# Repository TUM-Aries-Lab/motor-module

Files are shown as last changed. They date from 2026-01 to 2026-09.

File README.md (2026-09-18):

# Motor Control Software for Soft Exoskeleton



Motor control for the CubeMars AK60-6 actuator module used in Aries soft-exosuit development.

## Current Status

- Primary interface: CAN on Jetson Orin Nano via Linux SocketCAN
- Current maintained CAN path: MIT-only control
- Supported high-level helpers: `set_position()`, `set_velocity()`, `set_current()`, `stop()`
- UART support remains available for compatibility and earlier bring-up workflows

This repository is the motor-module codebase, not a full exosuit application. Its current focus is a modular actuator-control layer plus the bench-side scripts used to validate it.

## Key Features

- Transport-independent motor abstraction through `BaseMotor`
- Maintained SocketCAN backend for the CubeMars AK60-6
- MIT-only CAN control path with one consistent command model
- Background command refresh, feedback decoding, cached state handling, and staged recovery
- Bench-validation scripts for MIT mode, position stepping, velocity verification, and plotting

## Installation

For normal development, testing, and analysis:

```bash
uv sync --all-groups
source .venv/bin/activate
```

If you only want to install the package itself:

```bash
uv pip install -e .
```

## CAN Setup on Jetson Orin Nano

### Recommended: systemd startup

Install the tracked `can0.service` once so `can0` comes up automatically on boot:

```bash
sudo cp can0.service /etc/systemd/system/
sudo systemctl daemon-reload
sudo systemctl enable can0.service
sudo systemctl start can0.service
```

This brings `can0` up at 1 Mbps with bus-off auto-recovery.

Useful checks:

```bash
systemctl status can0.service
sudo systemctl restart can0.service
ip -details link show can0
```

### Manual setup

If you do not want to use the service, configure the interface manually:

```bash
sudo ./setup_can.sh
```

## Important Hardware Note

If the R-Link / UART cable is connected to the motor, CAN commands may be silently ignored even though feedback frames are still visible on the bus. For CAN operation, disconnect the UART cable and then reset the CAN interface.

## Recommended Workflow

### 1. Confirm MIT/CAN communication

```bash
sudo ./setup_can.sh
.venv/bin/python scripts/mit_mode_test.py --motor-id 0x03
```

### 2. Validate sustained velocity behavior

```bash
.venv/bin/python scripts/verify_set_velocity.py --motor-id 0x03 --velocity-erpm 3000
```

### 3. Run repeated MIT position stepping

```bash
.venv/bin/python scripts/mit_position_steps.py --motor-id 0x03 --duration 180 --angle-deg 50 --velocity-deg-s 100
```

### 4. Generate comparison plots from recorded CSV files

```bash
.venv/bin/python scripts/plot_graph.py velocity --data-root CSV --out-dir CSV/plots
.venv/bin/python scripts/plot_graph.py position --data-root CSV --out-dir CSV/plots
```

## Python API

The default convenience alias is the CAN motor class:

```python
from motor_python import Motor

with Motor(motor_can_id=0x03) as motor:
    motor.enable_mit_mode()
    motor.set_velocity(3000)
    motor.set_position(90.0)
    motor.stop()
```

For direct access to the specific implementations:

```python
from motor_python.cube_mars_motor_can import CubeMarsAK606v3CAN
from motor_python.cube_mars_motor import CubeMarsAK606v3
```

### Main CAN lifecycle methods

| Method | Purpose |
| --- | --- |
| `enable_mit_mode()` | Enter MIT mode |
| `disable_mit_mode()` | Exit MIT mode |
| `check_communication()` | Verify that the motor responds on the bus |
| `get_status()` | Return the latest cached `MotorState` |
| `close()` | Stop and close transport resources |

### Main CAN control methods

| Method | Purpose |
| --- | --- |
| `set_position(position_degrees)` | MIT-backed position command |
| `set_velocity(velocity_erpm)` | MIT-backed velocity command. Zero releases the motor via `stop()` |
| `set_current(current_amps)` | Interpreted as MIT torque feedforward |
| `set_mit_mode(pos_rad, vel_rad_s, kp, kd, torque_ff_nm)` | Direct MIT command |
| `stop()` | Neutral MIT command, disable MIT mode, release the motor |

## Useful Bench Scripts

These are the maintained scripts that matter most for the current implementation:

| Script | Purpose |
| --- | --- |
| `scripts/mit_mode_test.py` | Focused MIT/CAN protocol validation |
| `scripts/verify_set_velocity.py` | Bench verification of `set_velocity()` |
| `scripts/mit_position_steps.py` | Long-run MIT position stepping for bench tests |
| `scripts/plot_graph.py` | Chapter-4-style overlay and summary plots from recorded CSV files |
| `scripts/diagnose_can.py` | CAN bus diagnostics and recovery support |
| `scripts/scan_ids.py` | CAN ID discovery |
| `scripts/reset_degree.py` | Practical MIT recentering helper |

Additional exploratory and legacy scripts remain under `scripts/`, but they are not the primary maintained validation path.

## Testing

Run unit tests:

```bash
make test
```

Run CAN hardware tests:

```bash
make test-hardware-can
```

Run all hardware tests:

```bash
make test-hardware-all
```

## Project Structure

```text
can0.service                    systemd unit for automatic can0 startup
setup_can.sh                    manual CAN setup and reset helper
src/motor_python/               package source
scripts/                        bench and validation scripts
tests/                          unit and hardware-oriented tests
data/csv_logs/.gitkeep          placeholder for locally generated CSV logs
Test Rig CAD files/             CAD assets for the bench rig
```

## Notes on Scope

- The current CAN implementation is MIT-only.
- Legacy servo transport modes are intentionally not part of the maintained CAN path.
- The repository includes bench-validation tooling, but not thesis-only notes, temporary files, or local analysis artifacts.

## Run the Package Entry Point

```bash
uv run python -m motor_python
```

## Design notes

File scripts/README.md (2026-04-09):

# CAN Testing Scripts

Ad-hoc scripts for testing, diagnosing, and exercising the CubeMars AK60-6 motor over CAN.
These are **not** part of the main library or automated test suite — they are meant to be run
manually on the bench with the motor physically connected.

> **Current software status (2026-03-18): MIT-only CAN implementation.**
> For routine validation use `scripts/mit_mode_test.py` first.
> Duty/servo scripts in this folder are retained as historical diagnostics.

## Pre-conditions (all scripts)

```bash
# 1. Set PSU to 24 V and power-cycle the motor
# 2. Disconnect the UART / R-Link cable from the motor
# 3. Set up the CAN interface (run once per reboot)
sudo ./setup_can.sh

# 4. Activate the venv  — OR — prefix every script with .venv/bin/python scripts/<name>.py
source .venv/bin/activate
```

---

## Scripts

### `spin_test.py` (legacy)
Raw CAN demo — spins the motor forward for 2 s, pauses, then reverses for 2 s using
duty-cycle mode (arb_id 0x03). Prints live position/speed/current.

```bash
.venv/bin/python scripts/spin_test.py
```

---

### `motion_capture_test.py` (legacy)
Full motion-capture validation run — duty-cycle P-controller sine sweep (90 ± 30° at 6 s
period, 90 s total).  Logs telemetry to `data/logs/mocap_<timestamp>.csv`.

```bash
.venv/bin/python scripts/motion_capture_test.py
```

---

### `can_demo.py` (legacy exploration)
Exercises **every public method** of `CubeMarsAK606v3CAN` and prints PASS / FAIL / SKIP.
Use this to verify which modes work on the current firmware build.

```bash
.venv/bin/python scripts/can_demo.py
```

---

### `mit_mode_test.py`
Single-motor MIT protocol validation (CAN ID `0x03` by default). Exercises:
`enable_mit_mode`, `set_mit_mode`, `disable_mit_mode`, plus MIT-backed helpers
`set_position`, `set_velocity`, `set_current`, `stop`, and alias calls
`enable_motor` / `disable_motor`.

```bash
.venv/bin/python scripts/mit_mode_test.py
# If can0 is already configured and you don't want auto sudo reset:
.venv/bin/python scripts/mit_mode_test.py --skip-preflight
# Include velocity/current API sections (can spin the motor):
.venv/bin/python scripts/mit_mode_test.py --include-spin-tests
```

---

### `verify_set_velocity.py`
Focused validation for the `set_velocity()` API only.
It runs `start_ERPM -> 0 -> opposite_ERPM -> 0` (or start-direction only),
checks feedback sign/magnitude against the command, prints strict PASS/FAIL,
and logs each fresh feedback sample to CSV for mocap overlay.

```bash
.venv/bin/python scripts/verify_set_velocity.py --motor-id 0x03
# Signed range: -5000..5000 (starts in given direction, then reverses unless --forward-only)
.venv/bin/python scripts/verify_set_velocity.py --motor-id 0x03 --velocity-erpm -5000
# Skip automatic CAN reset if your interface is already configured:
.venv/bin/python scripts/verify_set_velocity.py --motor-id 0x03 --preflight-mode skip
# Forward-only check:
.venv/bin/python scripts/verify_set_velocity.py --motor-id 0x03 --forward-only
# Firmware-compatibility debug knobs:
.venv/bin/python scripts/verify_set_velocity.py --motor-id 0x03 --helper-policy fcfd --allow-legacy-feedback-ids
.venv/bin/python scripts/verify_set_velocity.py --motor-id 0x03 --feedback-can-id 0x2903
# Reduce velocity-loop aggressiveness if the bus drops under load:
.venv/bin/python scripts/verify_set_velocity.py --motor-id 0x03 --velocity-kd 0.12
# explicit CSV output path:
.venv/bin/python scripts/verify_set_velocity.py --motor-id 0x03 --csv-path data/csv_logs/verify_overlay.csv
```

---

### `mit_position_steps.py`
Long-run MIT position stepping script (ping-pong inside a safe angle window) so it can run for motion capture without hitting MIT position limits.
Primary knobs are still `--angle-deg`, `--duration`, and `--velocity-deg-s`.
Each command/feedback sample is also logged to CSV for direct comparison with mocap data.

```bash
# 3-minute mocap run (default behavior):
.venv/bin/python scripts/mit_position_steps.py --motor-id 0x03 --duration 180 --angle-deg 30 --velocity-deg-s 20

# faster stepping:
.venv/bin/python scripts/mit_position_steps.py --motor-id 0x03 --duration 180 --angle-deg 45 --velocity-deg-s 30

# custom sweep window (stays away from MIT hard limits):
.venv/bin/python scripts/mit_position_steps.py --motor-id 0x03 --duration 180 --angle-deg 30 --velocity-deg-s 20 --min-deg -600 --max-deg 600

# If can0 is already configured and you don't want auto reset:
.venv/bin/python scripts/mit_position_steps.py --motor-id 0x03 --duration 180 --angle-deg 30 --velocity-deg-s 20 --skip-preflight
# explicit CSV output path:
.venv/bin/python scripts/mit_position_steps.py --motor-id 0x03 --duration 180 --angle-deg 30 --velocity-deg-s 20 --csv-path data/csv_logs/mit_overlay.csv
```

> `mit_position_steps.py` uses the same kernel-level reset path as `setup_can.sh`
> for auto preflight (`berr-reporting on`, `restart-ms 100`).

---

### `reset_degree.py`
MIT-only practical reset helper: smoothly recenters the motor to a target degree
(default `0`) in MIT command space.

```bash
.venv/bin/python scripts/reset_degree.py --motor-id 0x03 --target-deg 0
# slower and gentler reset:
.venv/bin/python scripts/reset_degree.py --motor-id 0x03 --target-deg 0 --velocity-deg-s 10 --control-hz 15
# if can0 is already configured:
.venv/bin/python scripts/reset_degree.py --motor-id 0x03 --target-deg 0 --skip-preflight
```

---

### `quick_test.py`
Sends an enable command, listens for 3 s, and prints every unique CAN ID captured.
Useful for confirming the motor is on the bus and identifying the feedback ID.

```bash
.venv/bin/python scripts/quick_test.py
```

---

### `stress_test_can.py`
Runs 30 rounds of connect → enable → get_status → disable → close to verify the driver
is reliable under rapid reconnection and heavy use.

```bash
.venv/bin/python scripts/stress_test_can.py
```

---

### `diagnose_can.py`
Step-by-step diagnostic that tests each phase of the CAN connection independently:
CAN bus state → raw listen → filtered listen → enable/response → rapid cycles.
The script now reports **error-frame volume** explicitly, so `0x88` noise is
distinguished between real data frames and CAN error frames.

```bash
.venv/bin/python scripts/diagnose_can.py
```

---

### `scan_ids.py`
Scans CAN IDs 1–10 to discover which ID the motor is configured to use.
Run this if you don't know the motor's CAN ID.

```bash
.venv/bin/python scripts/scan_ids.py
```

---

### `drive_test.py`
Tries multiple duty formats, levels, and control modes (duty, current, velocity)
and records the feedback to characterise which modes the firmware supports.

```bash
.venv/bin/python scripts/drive_test.py
```

---

### `simple_test.py`
Minimal velocity spin helper for one motor: command one ERPM for one duration, then stop.
Use this when you only want to change speed and spin time quickly.

```bash
# default quick run
.venv/bin/python scripts/simple_test.py

# set only speed and duration
.venv/bin/python scripts/simple_test.py --velocity-erpm 4500 --duration 1.8

# reverse direction
.venv/bin/python scripts/simple_test.py --velocity-erpm -3000 --duration 1.2
```

---

### `tests/manual_our_implementation_test.py`
Manual integration script for the `CubeMarsAK606v3CAN` class API: enable,
feedback, velocity over 30 iterations. Good for iterating on the driver code.

```bash
.venv/bin/python tests/manual_our_implementation_test.py
```

---

### `tests/manual_servo_mode_test.py`
Legacy test using the third-party `TMotorCANControl` library's servo mode.
**Not for regular use** — kept for historical reference only.

```bash
.venv/bin/python tests/manual_servo_mode_test.py
```

---

## Two-Motor Setup (Second motor arriving Wednesday)

When the second motor arrives:
1. Set its CAN ID to **0x04** using CubeMars PC software.
2. The driver automatically assigns feedback ID `0x2904` for it.
3. Run the dual-motor demo:

```bash
.venv/bin/python -m motor_python --dual --motor-id-left 0x03 --motor-id-right 0x04
```

4. Hardware test (auto-skips until motor2 is connected):

```bash
make test-hardware-can   # includes TestCANDualMotor — skips if only one motor present
```

---

## Known Firmware Behaviour

| Mode | Works? | Notes |
|---|---|---|
| MIT (0x0803) | ✅ | Current production path in Python API |
| Duty/current/velocity/position servo frames | legacy | historical experiments only |

> Root cause of Speed=0 feedback: PSU must be **24 V**. At 18.5 V the H-bridge quietly
> locks out (error_code remains 0). Treat undervoltage and power integrity as first-line
> diagnostics when CAN feedback is present but commanded motion does not occur.

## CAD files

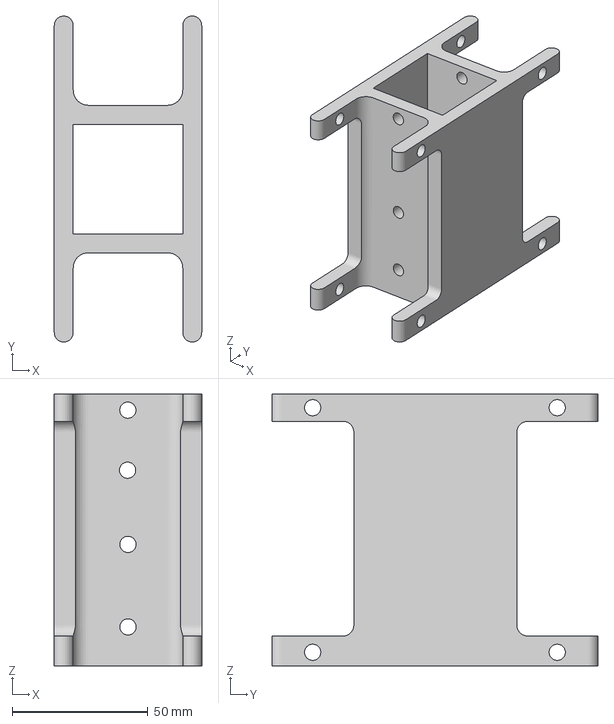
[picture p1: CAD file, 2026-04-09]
Test Rig CAD files/Rod_Adapter_Motor.3mf
54.3 x 120.0 x 100.0 mm

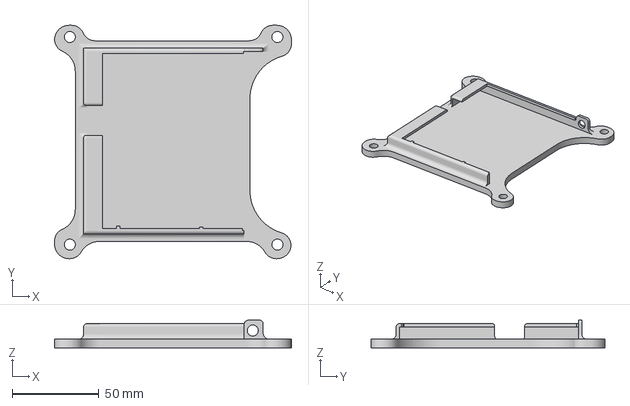
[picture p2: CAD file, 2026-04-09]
Test Rig CAD files/Jetson_Mount.3mf
137.0 x 135.0 x 16.0 mm

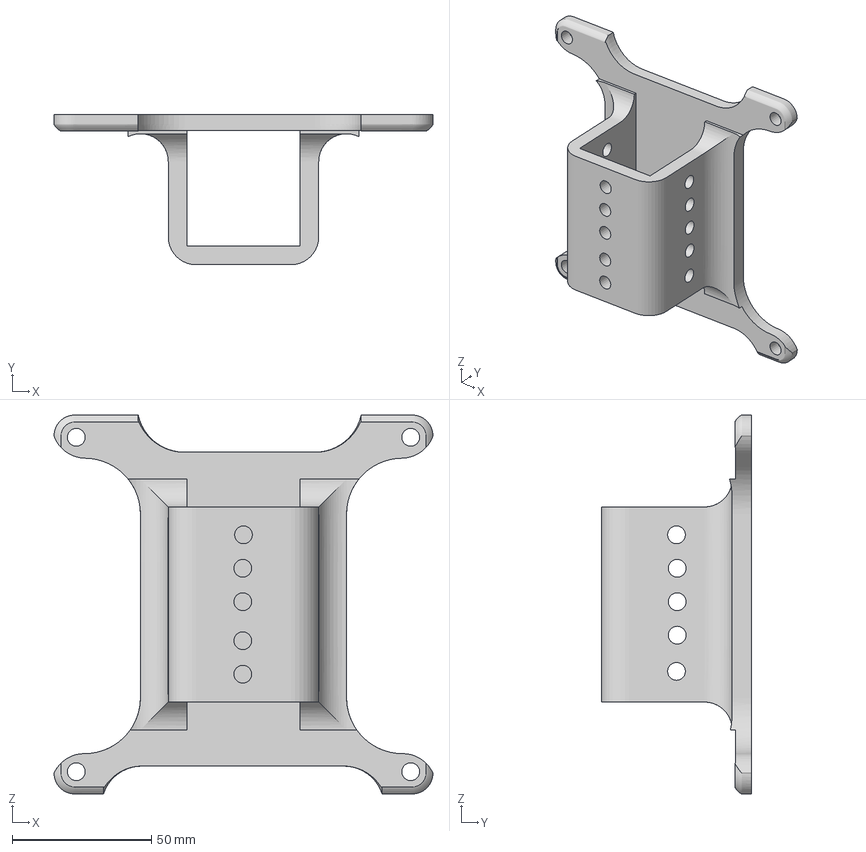
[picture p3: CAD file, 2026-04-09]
Test Rig CAD files/Rod_Adapter_Jetson.3mf
136.0 x 54.0 x 136.0 mm

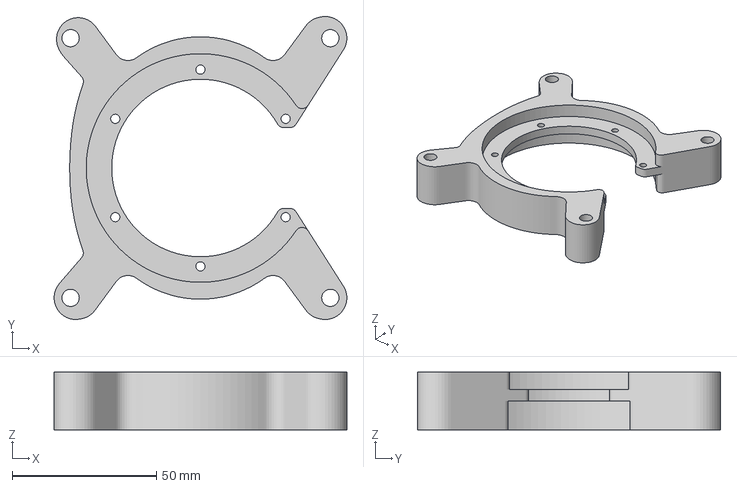
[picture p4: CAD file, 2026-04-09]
Test Rig CAD files/Motor_Case.3mf
101.4 x 105.0 x 20.0 mm

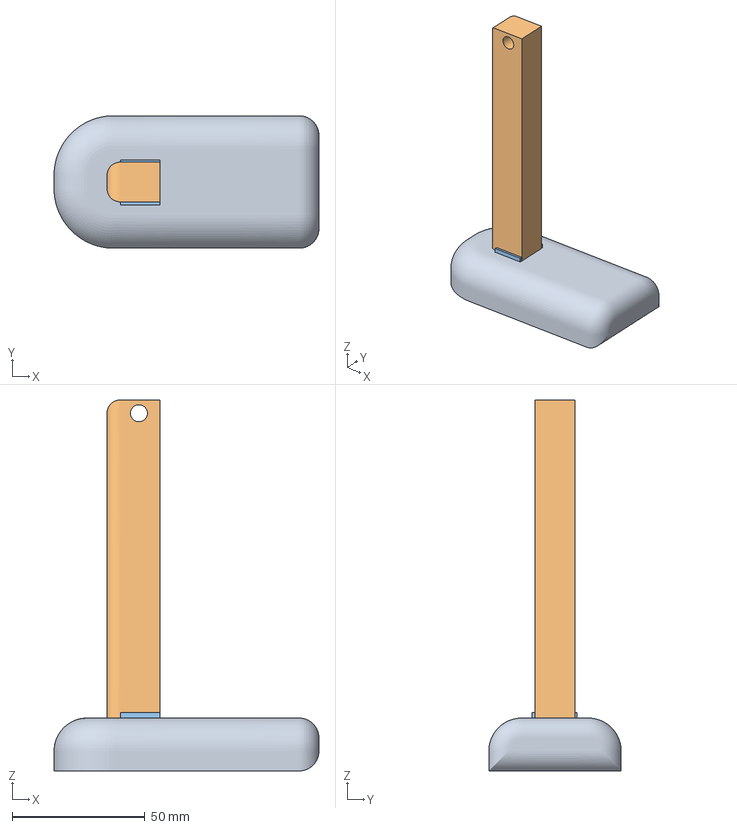
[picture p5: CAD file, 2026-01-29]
Test Rig CAD files/Foot.3mf
100.0 x 50.0 x 140.0 mm
Körper1
Körper2
Körper4

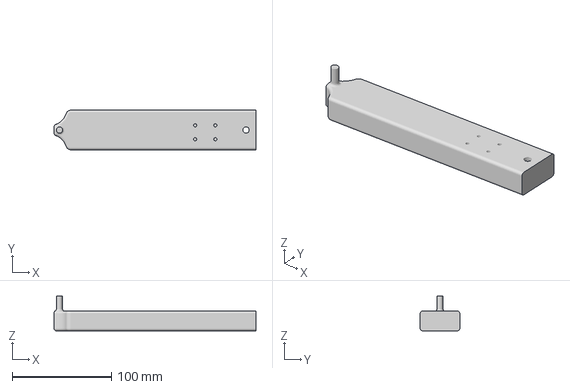
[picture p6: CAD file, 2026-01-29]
Test Rig CAD files/Leg_with_2_IMU's.3mf
203.4 x 40.0 x 35.0 mm

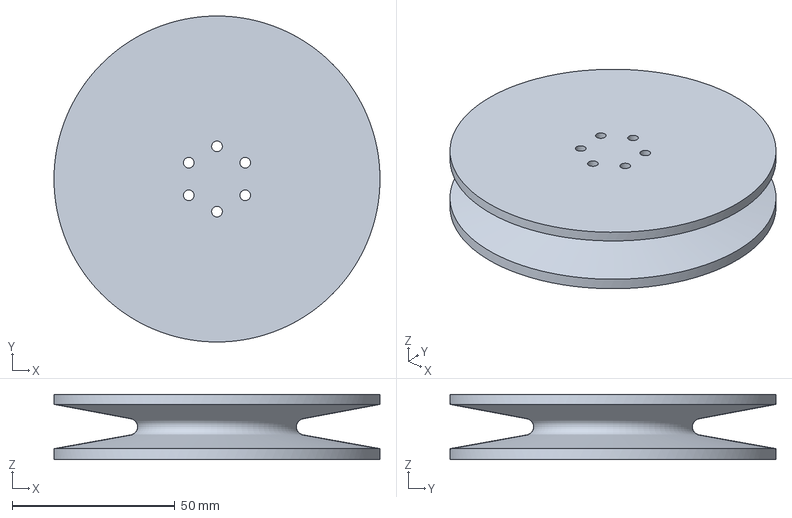
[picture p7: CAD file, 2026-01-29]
Test Rig CAD files/Spool_V2.3mf
100.0 x 100.0 x 20.0 mm

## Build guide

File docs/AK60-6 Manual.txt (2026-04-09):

AK Series Module Product Manual
                                        V3.0.1

              1 / 54
                        E-mail:info@cubemars.com
                       https://www.cubemars.com/

                                                               Content
Content....................................................................................................................................... 2
Precautions................................................................................................................................. 4
Product Features........................................................................................................................ 4
Disclaimer................................................................................................................................... 4
Version Change Record...............................................................................................................5
1. Driver Product Information.................................................................................................... 7
   1.1Driver Appearance Introduction & Product Specifications(small).................................... 7
   1.2Driver Appearance Introduction & Product Specifications(big)........................................8
   1.2Driver Interface and Definition..........................................................................................9
       1.2.1Driver Interface Diagram............................................................................................ 9
       1.2.2Driver Interface Pin Definition....................................................................................9
       1.2.3Recommended Brands and Models for Driver Interface........................................... 9
   1.3 Driver Indicator Light Definition..................................................................................... 10
   1.4         Main Accessories and Specifications........................................................................ 10
2.Connection.............................................................................................................................12
   2.1 R-link Appearance Introduction, Product Specifications, and Interface Definition....... 12
   2.3 R-link Indicator Light Definition......................................................................................13
   2.4Driver and R-link Connection and Precautions................................................................13
3.Upper Computer Instructions................................................................................................14
   3.1Upper Computer Interface and Instructions................................................................... 14
       3.1.1Configuration............................................................................................................ 15
       3.1.2Real-time Status........................................................................................................19
       3.1.3Real-time Data.......................................................................................................... 20
       3.1.4Chinese-English Switch............................................................................................. 20
       3.1.5Control...................................................................................................................... 21
       3.1.6Connect.....................................................................................................................23
       3.1.7Stop...........................................................................................................................23
   3.2Driver Board Calibration.................................................................................................. 23
       3.2.1 Calibration Steps......................................................................................................23
   3.3Control Demonstration....................................................................................................24
                                                                     2 / 54
                                                                                                            E-mail:info@cubemars.com
                                                                                                           https://www.cubemars.com/

     3.3.1Servo Mode...............................................................................................................24
     3.3.2Force Control(MIT) Mode.........................................................................................28
  3.4Firmware Update.............................................................................................................30
4. Driver Board Communication Protocol and Instructions..................................................... 31
  4.1Servo Mode Control Mode and Instructions...................................................................31
     4.1.1Duty Ratio Mode.......................................................................................................32
     4.1.2Current Loop Mode.................................................................................................. 33
     4.1.3Current Brake Mode................................................................................................. 33
     4.1.4Velocity Loop Mode..................................................................................................35
     4.1.5Position Loop Mode..................................................................................................35
     4.1.6Setting Origin Mode................................................................................................. 36
     4.1.7Position Velocity Loop Mode....................................................................................37
  4.2Force Control Mode Communication Protocol............................................................... 37
  4.3Motor Message Format................................................................................................... 42
     4.3.1 CAN Upload Message Protocol................................................................................42
     4.3.2Serial Port Message Protocol....................................................................................43
  4.4Control Command Examples........................................................................................... 52
     4.4.1 CAN Port Control Command Examples....................................................................52
     4.4.2Serial Port Control Command Examples.................................................................. 53

                                                              3 / 54
                                                                                                   E-mail:info@cubemars.com
                                                                                                  https://www.cubemars.com/

Precautions
1.Ensure that there are no short circuits in the circuit and that interfaces are connected correctly
as required.

2.    The driver board will heat up during output; please use it carefully to avoid burns.

3.    Before use, please check if all parts are intact. If any parts are missing or aged, please stop
using it and contact technical support in time.

4.     Please strictly follow the working voltage, current, temperature, and other parameters
specified in this document; otherwise, it will cause permanent damage to the product!

Product Features
The AK series motor driver board adopts high-performance drive chips in the same class, uses
Field Oriented Control (FOC) algorithm, and is equipped with advanced self-disturbance control
technology for speed and angle control. It can be used with CubeMarsTool parameter setting
software for parameter setting and firmware upgrades. In terms of hardware, the inner loop uses
a 16-bit high-precision encoder, supporting up to 21 bits (custom firmware required), and the
CAN communication uses a safer isolated CAN interface, along with a more reliable plug, greatly
enhancing the reliability of the product's use and communication; in terms of software, the
upper computer CubeMarsTool has been fully upgraded, and there is no need to switch between
servo mode and force control mode, the control interface is more concise, and a large number of
simplifications have been made in the operation, fully improving the customer's experience.

Disclaimer
Thank you for purchasing the AK series modular motor. Before using it, please read this
statement carefully. Once used, it is considered as recognition and acceptance of all the contents
of this statement. Please strictly follow the product manual and relevant laws, regulations,
policies, and guidelines for the installation and use of the product. During the use of the product,
the user promises to be responsible for their own actions and all consequences arising
therefrom.

Any losses caused by improper use, installation, or modification of the product by the user,
CubeMars will not assume legal responsibility.

CubeMars is a trademark of Nanchang Kude Intelligent Technology Co., Ltd. and its affiliated
companies. The product names and brands mentioned in this document are trademarks of the
companies. This product and manual are copyrighted by Nanchang Kude Intelligent Technology
Co., Ltd. No copying or reprinting is allowed without permission. The final interpretation of the

                                                  4 / 54
                                                                           E-mail:info@cubemars.com
                                                                          https://www.cubemars.com/

disclaimer belongs to Nanchang Kude Intelligent Technology Co., Ltd.

Version Change Record
            Date                            Version                            Change
                                                                  1.First compile
         2023.10.18                         Ver.2.0.0             2.Driver version :V3.0
                                                                  3.CubeMarsTool version:V2.0
                                                                  1.1Changed the maximum
                                                                  working voltage to the
                                                                  allowable working voltage
                                                                  range
                                                                  4.1.6Modified the example
         2024.07.29                         Ver.2.0.1             code for setting the origin
                                                                  4.2 Modified the motion
                                                                  control protocol example code
                                                                  4.3.2.1 Corrected the outer
                                                                  loop position formula

                                                                  Modified the cover logo
                                                                  1 Modified driver board
                                                                  product information
                                                                  2 Added section content
         2024.08.06                         Ver.2.0.2
                                                                  3.4Corrected the firmware
                                                                  update example picture
                                                                  4.2 Modified parameter range

                                                                  1.2.2 Corrrect drive interface
                                                                  definition
                                                                  2. Correct R-Link definition
                                                                  2.1 Add VCC voltage selction
         2024.12.04                         Ver.2.0.3             switch,modify R-link
                                                                  specifications
                                                                  3.Change CubeMars’s
                                                                  ownership to Nanchang Kude
                                                                  Intelligent Technology CO., Ltd.
                                                                  The formal version change
         2024.12.11                         Ver.3.0.0
                                                                  to3.0.0
                                                                  4.2 Add AKE60-8 and AKE80-8
                                                                  motor parameters and correct
         2025.03.14                        Ver. 3.0.1
                                                                  MIT control code routines
                                                                  4.3.2 Modify serial port control

                                              5 / 54
                                                                         E-mail:info@cubemars.com
                                                                        https://www.cubemars.com/

         data description

6 / 54
                E-mail:info@cubemars.com
               https://www.cubemars.com/

1. Driver Product Information

1.1Driver Appearance Introduction&Product Specifications（Small Size）

                                                      ①Three-phase wires connection port

                                                      ②Hardware version

                                                      ③Connection port

                                                      ④Mounting holes

                                Production specifications（small size）

      Rated working voltage                            48V

      Allowable working voltage                        18-52V

      Rated working current                            10A

      Maximum current                                  30A

      Standby power consumption                        ≤50mA

      CAN bus bit rate                                 1Mbps

      Size                                             54mm×54mm

      Working environment temperature                  -20℃ to 65℃

      Maximum allowable temperature for
                                                       100℃
control board

      Inner loop encoder bits                          21bit（single turn absolute）

     Outer loop encoder bits (limited to dual
                                                       15bit（single turn absolute）
encoder model)

                                             7 / 54
                                                                         E-mail:info@cubemars.com
                                                                        https://www.cubemars.com/

1.2Driver Appearance Introduction&Product Specifications（Big Size）

                                                           ①Three-phase wires connection

                                                    port

                                                           ②Hardware version

                                                           ③Connection Port

                                                           ④Mounting holes

                                Product Specifications（Big size）

      Rated working voltage                                48V

      Allowable working voltage                            18-52V

      Rated working current                                20A

      Maximum current                                      60A

      Standby power consumption                            ≤50mA

      CAN bus bit rate                                     1Mbps

      Size                                                 63mm×57mm

      Operation environment temperature                    -20℃ to 65℃

      Maximum allowable temperature for
                                                           100℃
control board

      Inner loop encoder bits                              21bit（single turn absolute）

     Outer loop encoder bits (limited to dual
                                                           15bit（single turn absolute）
encoder model)

                                           8 / 54
                                                                        E-mail:info@cubemars.com
                                                                       https://www.cubemars.com/

1.2 Driver Interface and Definition

1.2.1 Driver Interface Diagram

                                        Small Size

                                         Big Size

1.2.2 Driver Interface Pin Definition

                                           9 / 54
                                                      E-mail:info@cubemars.com
                                                     https://www.cubemars.com/

1.2.3 Recommended Brands and Models for Driver Interface

1.3Driver Indicator Light Definitions

                                       Indicator Light

            1.Power Indicator     Light on          The driver board is powered
            Light (Blue when
                                  Light off       The driver board is not powered
                  lit)）
              2.Operation         Light on               The motor is working
             Indicator Light
                                  Light off             The motor is not working
            (Green when lit)
              3.Drive Fault       Light on                 Driver board fault
           Indicator Light (Red
                                  Light off        Driver board function normally
                when lit)

⚠：After the driver board is powered, the blue light should remain on in the normal
state, and the green and red lights should light up for 2 seconds before going out.

                                              10 / 54
                                                                           E-mail:info@cubemars.com
                                                                          https://www.cubemars.com/

1.4 Main Accessories and Specifications

No.   Item                             Specifications                     Quantity   Remarks
                              16AWG - Red and black silicone wire and
                     Power             white and blue - Teflon
                                                                            1PCS
 1                   and      30#-OD0.64-100±10mm-4-XT30(2+2)-F-on                      ±2MM
                               e end connector XT30(2+2)-F,the other        Each
      Power and      CAN
                                  end stripped and tinned 3±1mm
      signal plug    cable
                     Serial                  Teflon30#
                     port     Wire OD0.64-200±10mm-3-GH1.25-3PINm           1PCS
 2                   cable                                                  Each        ±2MM
                              ale to FC crimp terminal horn plug 2*4PIN
 3    Thermistor                MF51B103F3950-10K-3950                      2PCS
                                                                                       AK10-9
      Electrolytic                                                                       V3.0
 4     capacitor                   120Uf-63V-10x12MM                        2PCS
                                                                                      standard
 5    Power MOS                HYG035N08NS2C2-80V-2.8mΩ                    12PCS

                                            11 / 54
                                                                       E-mail:info@cubemars.com
                                                                      https://www.cubemars.com/

2.Connection

2.1 R-link Appearance Introduction&Product Specifications and Interface

Definition

                                        Product Specifications

         Rated working voltage                            5V

         VCC voltage selection switch                     3.3v (default)

         Standby power consumption                        ≤30mA

         Size                                             73.8x23.6x14.5MM

         Working environment temperature                  -20℃ to 65℃

          Maximum Allowable Temperature for
                                                          85℃
    Control Board

           Interface
No                           Pin        Description
           Function
                             1          Serial signal imput（RXD）
                             2          Serial signal output（TXD）
                             3          Serial signal ground (GND)
           Serial            4          VCC power output（VCC）
1
           Interface         5          Data sent request（RTS）
                             6          Clear to send（CTS）
                             7          Power ground（GND）
                             8          5V Power output（5V）

                                                12 / 54
                                                                            E-mail:info@cubemars.com
                                                                           https://www.cubemars.com/

2.2 R-link Indicator Light Definitions

 No.                             Color                           Description

                                                                 PWR Power Indicator,
                                                                 indicates the power status of
                                                                 the R-link. Under normal
                                                                 conditions, it will light up red
                                                                 when power is connected. If
 1                               Red
                                                                 it does not light up when
                                                                 power is connected, please
                                                                 remove the power source
                                                                 immediately and do not
                                                                 attempt to power on again.
                                                                 TXD Serial Communication
                                                                 Output (TX), usually off,
 2                               Red                             blinks when there is data
                                                                 output from the R-link serial
                                                                 port.
                                                                 RXD Serial Communication
                                                                 Input (RX), usually off, blinks
 3                               Red
                                                                 when there is data input to
                                                                 the R-link serial port.

2.3 Driver and R-link Connection and Precautions

- USB on R-Link ---> PC End
- 8 Pin Port ---> RLink 8Pin Port End
- 3Pin Terminal (UART interface) ---> 3Pin Port on Motor(UART)

                                             13 / 54
                                                                         E-mail:info@cubemars.com
                                                                        https://www.cubemars.com/

3.Upper Computer Instruction

3.1Upper Computer Interface and Explanation

A. Configuration
B. Real-time Status
C. Real-time Data
D. Chinese-English Switch
E. Control
F. Connection
G. Stop

                                14 / 54
                                               E-mail:info@cubemars.com
                                              https://www.cubemars.com/

3.1.1 Configuration

3.1.1.1 Basic Settings

The Basic Settings interface allows users to configure motor parameters and communication
parameters; The Motor Settings section supports motor parameter identification, encoder
parameter calibration, and parameter reading and writing. For specific motor calibration
operations, see section 3.2. The Application Settings section supports settings for CAN port mode,
CAN bus rate, CAN feedback rate, CAN ID, and serial port baud rate, which users can match
according to actual conditions.

The CAN port mode is divided into two types: periodic feedback and query-reply. Periodic
reporting will provide messages at regular intervals based on the CAN feedback rate; the
query-reply mode only sends back message reports when the motor receives the correct control
commands.

                               ：Perform motor parameter identification, which can be observed in

the position curve to see if the motor is moving. After identification, it will automatically stop and
update the motor parameters to the upper computer.

                                                15 / 54
                                                                            E-mail:info@cubemars.com
                                                                           https://www.cubemars.com/

⚠ ： The entire process of motor parameter identification should be kept under no-load
conditions; otherwise, it may lead to inaccurate identification parameters or motor damage.
The identification process will start with a sharp, short sound, then the motor starting to rotate
with a louder noise.

                                ：Perform encoder parameter identification, which can be observed

in the position curve to see if the motor is moving. After identification, it will automatically stop
and update the encoder parameters to the upper computer.

⚠ ： The entire process of motor parameter identification should be kept under no-load
conditions; otherwise, it may lead to inaccurate identification parameters or motor damage.
The identification process will start with a sharp, short sound. Performing this process
consecutively multiple times can cause the motor temperature to rise sharply.

                    ：Read the motor parameters and encoder parameters from the driver board

to the upper computer.

                    ： Write the motor parameters and encoder parameters from the upper

computer to the driver board.

3.1.1.2 Advanced Settings
⚠ ： Warning. Note that customers who are using this product for the first time should not
arbitrarily modify the parameters in the advanced settings, otherwise, the motor may run
abnormally.

                                               16 / 54
                                                                           E-mail:info@cubemars.com
                                                                          https://www.cubemars.com/

The Advanced Settings interface allows users to customize more parameters according to their
needs. In addition to the parameter reading and writing functions, it also provides parameter
restoration, loading, and exporting functions.

             Read Parameters: Click to read the parameters from the driver board to the upper

computer.

             Click to write the current upper computer parameters to the driver board.

⚠：Before rewriting motor parameters, be sure to read the parameters first; otherwise, other
motor parameters will be incorrect. If this happens, please download the APP parameters for
the corresponding motor from the official website, and then write the default parameters of
the motor through "Load from file"

             Click to restore the upper computer parameters to the default values for the

corresponding model.

                                            17 / 54
                                                                       E-mail:info@cubemars.com
                                                                      https://www.cubemars.com/

                  Load the parameter file into the upper computer; click and select the

parameter file for the corresponding motor model, which comes in two formats: .AppParams
and .McParams.

               Export parameters：Click to export parameters, select the save file, and you will

obtain a custom parameter file.

⚠：Please strictly use the specified voltage, current, power, and temperature. Our company will
not assume any legal responsibility for personal injury or irreversible damage to the driver
board and motor caused by the improper operation of this product.

                                            18 / 54
                                                                       E-mail:info@cubemars.com
                                                                      https://www.cubemars.com/

3.1.1.3 Firmware Upgrade

The Firmware Upgrade interface includes three sections: Firmware Information, Upgrade Options,
and Upgrade Progress. Customers can upgrade firmware based on their own needs. For specific
steps on upgrading the firmware, see section 3.4.

3.1.2 Real-time Status

The Real-time Status interface displays the current software and hardware versions, motor
firmware version, motor parameter status, operating mode, and fault status.

                                            19 / 54
                                                                      E-mail:info@cubemars.com
                                                                     https://www.cubemars.com/

3.1.3 Real-time Data

This page supports viewing real-time data feedback and debugging interface, as well as plotting
graphs. The data includes:
-DQ: DQ voltage represents the motor voltage converted onto the D-axis and Q-axis, and DQ
current represents the motor current converted onto the D-axis and Q-axis.
- Current: Current in indicates the motor's input current, Current motor indicates the motor's
phase line current, and Duty cycle indicates the motor's duty ratio.
- Temperature: Temperature MOSFET indicates the temperature of the motor's MOS transistor,
and Temperature Motor indicates the motor's temperature.
- Speed: ERPM indicates the electrical rotational speed of the motor's rotor.
- Position: Position indicates the position of the motor's rotor.
- Encoder Angle: Encoder angle indicates the angle of the encoder.

3.1.4 Chinese-English Switch

The upper computer currently supports switching between Chinese and English languages. Click
on "中" or "EN" in the red box in the upper right corner of the interface to switch languages.

                                              20 / 54
                                                                          E-mail:info@cubemars.com
                                                                         https://www.cubemars.com/

3.1.5 Control

3.1.5.1 Servo Control

                        ： In the position-velocity loop mode, the motor can be set to positions
ranging from -36000° to 36000°;

                        ： In the position-speed loop mode, the motor can be set to positions
ranging from 0 to 359°;

                        ：The motor will set the current rotor position as the zero position;

                        ：The motor rotates to the zero position. (The motor will operate at the
maximum speed, pay attention to safety)

      ：The corresponding mode start button.

                                               21 / 54
                                                                           E-mail:info@cubemars.com
                                                                          https://www.cubemars.com/

3.1.5.2   Force Control (MIT) Control

Force control mode (motion control mode, MIT MODE) offers three different control modes:
position, speed, and torque loops, which are determined by the data sent. For specific operation
methods, see section 3.3.2.

3.1.5.3 Unit Settings

                                    :Each button corresponds to the unit that needs to be
converted, supporting the conversion display of rotational speed (RPM, ERPM, rad/s, Dps).

                                    :Enter the number of motor poles, as shown in the left figure,
14 is the number of pole pairs.

                                   :Enter the motor reduction ratio.

                                              22 / 54
                                                                         E-mail:info@cubemars.com
                                                                        https://www.cubemars.com/

3.1.6 Connection

The Connection module can configure serial communication, as shown in the left figure. First,
click "Refresh", then select the communication baud rate, choose the correct port, and finally
"Connect" of the motor. The display changes from "Not connected" to "Connected to COMX"
indicating a successful serial connection. As shown in the right figure, click "Disconnect" to
disconnect the communication.

3.1.7 Stop

The experimental stop button, when clicked, will stop the motor's working.

3.2 Driver Board Calibration
When you have reinstalled the driver board on the motor, changed the wiring sequence of the
motor's three-phase lines, or updated the firmware, recalibration is necessary (it was calibrated
when it left the factory for the first time, no need to calibrate again). After calibration, the motor
can be used.

3.2.1 Calibration Steps

                                                23 / 54
                                                                            E-mail:info@cubemars.com
                                                                           https://www.cubemars.com/

STEP0:
Ensure that the motor's power supply is stable, the connectors are properly connected, and
successfully connected to the upper computer, then enter the system settings page.
STEP1:
Click "Read" and wait for the connection interface to display.
                               ；
STEP2:
Click "Motor Identification", after a brief beep                            ； the motor will start
rotating. Wait for about 10 seconds                     before   the     motor stops rotating.
                             When the display appears, it indicates that the motor parameter
identification process is complete.

STEP3:
Click "Encoder Identification", the motor will rotate slowly. Wait for about 45 seconds, and when
the connection interface display is complete                               the encoder parameter
identification is finished.

STEP4:
Click      "Write",    and      when        the         connection      interface     display     is
complete                                 the calibration is finished.

⚠：The entire process of motor parameter and encoder parameter identification should be kept
under no-load conditions; otherwise, it may lead to inaccurate identification parameters or
motor damage. The encoder parameter identification process generates heat, and performing
this process consecutively multiple times can cause the motor temperature to rise sharply.

3.3 Control Demonstration
After confirming that the motor power supply and load are correctly installed, the wiring is
correct, and the driver board calibration is complete, you can start using the motor. Below are
explanations for the use of servo control and force control modes.

3.3.1 Servo Mode

3.3.1.1 Multi-Position-Velocity Loop Mode
Ensure that the motor input power is stable, the connectors are properly connected, and
successfully connected to the upper computer. In the "Servo Control" interface, click on "Multi
Mode," enter the desired position (at this time, the position is ± 100 turns, i.e., -36000 °
-36000 ° ), desired speed, and acceleration. The motor will move at the desired speed until it
reaches the desired position.

                                              24 / 54
                                                                            E-mail:info@cubemars.com
                                                                           https://www.cubemars.com/

3.3.1.2 Single-Position-Velocity-Loop Mode Mode
Ensure that the motor input power is stable, the connectors are properly connected, and
successfully connected to the upper computer. In the "Servo Control" interface, click on "Single
Mode," enter the desired position (at this time, the position is only one turn, i.e., 0 ° -359 ° ),
desired speed, and acceleration. The motor will move at the desired speed until it reaches the
desired position.

3.3.1.3 Braking Mode
Ensure that the motor input power is stable, the connectors are properly connected, and
successfully connected to the upper computer. In the "Servo Control" interface, enter the desired
torque T, and the motor will brake with the desired torque.

                                              25 / 54
                                                                          E-mail:info@cubemars.com
                                                                         https://www.cubemars.com/

3.3.1.4 Position Loop Mode
Ensure that the motor input power is stable, the connectors are properly connected, and
successfully connected to the upper computer. In the "Servo Control" interface, enter the desired
position P, and the motor will reach the desired position with maximum speed and acceleration.

3.3.1.5 Current Loop Mode

Ensure that the motor input power is stable, the connectors are properly connected, and
successfully connected to the upper computer. In the "Servo Control" interface, enter the
desired current I, and the motor will operate at the desired current.

                                             26 / 54
                                                                         E-mail:info@cubemars.com
                                                                        https://www.cubemars.com/

3.3.1.6 Velocity Loop Mode
Ensure that the motor input power is stable, the connectors are properly connected, and the
motor is in servo mode. After successfully connecting to the upper computer, in the "Servo
Control" interface, enter the desired speed S (±50000 ERPM), and the motor will operate at the
desired speed (with the default maximum acceleration).

3.3.1.7 Braking Loop Mode
Ensure that the motor input power is stable, the connectors are properly connected, and
successfully connected to the upper computer. In the "Servo Control" interface, enter the desired
braking current B, and the motor will brake with the desired current.

                                             27 / 54
                                                                        E-mail:info@cubemars.com
                                                                       https://www.cubemars.com/

3.3.1.8 Duty Cycle Mode
Ensure that the motor input power is stable, the connectors are properly connected, and the
motor is in servo mode. After successfully connecting to the upper computer, in the "Servo
Control" interface, enter the desired duty cycle (default 0.005-0.95), and the motor will operate
at the desired duty cycle.

3.3.2 Force Control Mode(Mit Control)

3.3.2.1Force Control Position Mode
Ensure that the motor input power is stable, the connectors are properly connected, and
successfully connected to the upper computer. In the "MIT Control" interface, enter the
corresponding "CAN ID," desired position, and KP, KD, then click "Start," and the motor will move
to the desired position. (The motor operates with a specified position and Kp, Kd values, turning
                                             28 / 54
                                                                        E-mail:info@cubemars.com
                                                                       https://www.cubemars.com/

towards the specified position)

3.3.2.2 Force Control Velocity Mode
Ensure that the motor input power is stable, the connectors are properly connected, enter the
desired speed S and KD, then click "Start," and the motor will operate at the specified speed. (The
motor operates with a specified speed and Kd value, rotating at the specified speed)

3.3.2.3 Force Control Torque Mode
Ensure that the motor input power is stable, the connectors are properly connected, enter the
desired torque T, then click "Start," and the motor will operate at the specified torque. (The
motor operates with a specified torque value, rotating at the specified torque value)
                                              29 / 54
                                                                          E-mail:info@cubemars.com
                                                                         https://www.cubemars.com/

3.4Firmware Update

1. Select the corresponding firmware from the drop-down list.
2. Click "Jump to IAP."
3. Click "Upload" and wait for the upgrade progress bar to reach 100%.
4. Click "Jump to App," wait for 5 seconds, the motor enters the operating mode, and the
firmware update is complete.

                                         30 / 54
                                                                  E-mail:info@cubemars.com
                                                                 https://www.cubemars.com/

4. Driver Board Communication Protocol and Description

4.1Servo Mode Control Modes and Description

There are 6 control modes in the servo mode, each corresponding to a specific ID number.

Duty Cycle Mode: A specified duty cycle voltage is given to the motor, similar to square wave
drive form;
Current Loop Mode: A specified Iq current is given to the motor, and since the motor output
torque = iq*KT, it can be used as a torque loop (KT data can be referenced on the official
website);
Current Brake Mode: A specified braking current is given to the motor to hold it in the current
position (pay attention to motor temperature when using);
Velocity Mode: A specified operating speed is given to the motor (acceleration is default to the
maximum value);
Position Mode: A specified position is given to the motor, and the motor will move to the
specified position (speed and acceleration are default to the maximum value);
Position-Velocity Loop Mode: A specified position, speed, and acceleration are given to the
motor.

Servo mode driver board data transmission definition
Identifier: Control Mode ID + Driver ID        Frame Type: Extended Frame
Frame Format: DATA                        DLC: 8 bytes
The servo motor protocol is a CAN protocol, using an extended frame format as shown below:

Can ID bits               [28]-[8]                               [7]-[0]
Field name (Function      Control mode ID （Control               Drive ID （Driver ID）
Definition)               ModeID）

Control mode has{0,1,2,3,4,5,6}      7 characteristic values corresponding to 7 control modes.

Duty Cycle Mode: 0
Current Loop Mode: 1
Current Brake Mode: 2
Velocity Mode: 3
Position Mode: 4
Set Origin Mode: 5
Position-Speed Loop Mode: 6

The following provides examples of controlling the motor in various modes.

                                               31 / 54
                                                                            E-mail:info@cubemars.com
                                                                           https://www.cubemars.com/

Below are library call, function and macro definitions for various instances.
typedef enum {
     CAN_PACKET_SET_DUTY = 0,                // Duty Cycle Mode
     CAN_PACKET_SET_CURRENT,                 // Current Loop Mode
     CAN_PACKET_SET_CURRENT_BRAKE,             // Current Brake Mode
     CAN_PACKET_SET_RPM,                      // Speed Mode
     CAN_PACKET_SET_POS,                       // Position Mode
     CAN_PACKET_SET_ORIGIN_HERE,               // Set origin position mode (zero mode)
     CAN_PACKET_SET_POS_SPD,                   // Position-Velocity Loop Mode
} CAN_PACKET_ID;

void comm_can_transmit_eid(uint32_t id, const uint8_t *data, uint8_t len) {
     uint8_t i=0;
     if (len > 8) {
           len = 8;
     }
     CanTxMsg TxMessage;
     TxMessage.StdId = 0;
     TxMessage.IDE = CAN_ID_EXT;
     TxMessage.ExtId = id;
     TxMessage.RTR = CAN_RTR_DATA;
     TxMessage.DLC = len;
     for(i=0;i<len;i++)
           TxMessage.Data[i]=data[i];
     CAN_Transmit(CHASSIS_CAN, &TxMessage); //CAN port trasmissionTxMessage Data Can
port sends TxMesage Data
}

void buffer_append_int32(uint8_t* buffer, int32_t number, int32_t *index) {
     buffer[(*index)++] = number >> 24;
     buffer[(*index)++] = number >> 16;
     buffer[(*index)++] = number >> 8;
     buffer[(*index)++] = number;
}

void buffer_append_int16(uint8_t* buffer, int16_t number, int16_t *index) {
     buffer[(*index)++] = number >> 8;
     buffer[(*index)++] = number;
}

4.1.1 Duty Cycle Mode
Duty Cycle Mode Data Transmission Definition

                                               32 / 54
                                                                          E-mail:info@cubemars.com
                                                                         https://www.cubemars.com/

    Data Bit             Data[0]              Data[1]              Data[2]               Data[3]

     Range               0~0xff                0~0xff              0~0xff                 0~0xff

 Corresponding        Duty Cycle Bit       Duty Cycle Bit      Duty Cycle Bit         Duty Cycle Bit
    Variable             25-32                17-24                9-16                    1-8

void comm_can_set_duty(uint8_t controller_id, float duty) {
     int32_t send_index = 0;
     uint8_t buffer[4];
     buffer_append_int32(buffer, (int32_t)(duty * 100000.0), &send_index);
     comm_can_transmit_eid(controller_id |
                    ((uint32_t)CAN_PACKET_SET_DUTY << 8), buffer, send_index);
}

4.1.2 Current Loop Mode
Current Loop Mode Data Transmission Definition

    Data Bit             Data[0]              Data[1]              Data[2]               Data[3]

     Range               0~0xff                0~0xff              0~0xff                 0~0xff

 Corresponding
                    Current Bit 25-32     Current Bit 17-24    Current Bit 9-16       Current Bit 1-8
    Variable
The current value is of int32 type, and the values -60000 to 60000 represent -60 to 60 A.
Current Loop Mode Send Example Routine

void comm_can_set_current(uint8_t controller_id, float current) {
     int32_t send_index = 0;
     uint8_t buffer[4];
     buffer_append_int32(buffer, (int32_t)(current * 1000.0), &send_index);
     comm_can_transmit_eid(controller_id |
                    ((uint32_t)CAN_PACKET_SET_CURRENT << 8), buffer, send_index);
}

4.1.3 Current Brake Mode
 Current Brake Mode Data Transmission Definition

   Data Bit           Data[0]               Data[1]                Data[2]               Data[3]

    Range              0~0xff                0~0xff                0~0xff                 0~0xff

Corresponding    Brake Current Bit      Brake Current Bit     Brake Current Bit     Brake Current Bit
   Variable           25-32                  17-24                  9-16                   1-8

                                               33 / 54
                                                                              E-mail:info@cubemars.com
                                                                             https://www.cubemars.com/

The brake current value is of int32 type, and the values 0 to 60000 represent 0 to 60 A.
 Current Brake Mode Send Example Routine

void comm_can_set_cb(uint8_t controller_id, float current) {
     int32_t send_index = 0;
     uint8_t buffer[4];
     buffer_append_int32(buffer, (int32_t)(current * 1000.0), &send_index);
     comm_can_transmit_eid(controller_id |
               ((uint32_t)CAN_PACKET_SET_CURRENT_BRAKE << 8), buffer, send_index);
}

                                               34 / 54
                                                                           E-mail:info@cubemars.com
                                                                          https://www.cubemars.com/

4.1.4 Velocity Loop Mode
Simplified Control Diagram for Velocity Loop

Velocity Loop Mode Data Transmission Definition

     Data Bit                  Data[0]              Data[1]             Data[2]               Data[3]

       Range                    0~0xff              0~0xff               0~0xff                0~0xff

Corresponding
                           Speed Bit 25-32     Speed Bit 17-24      Speed Bit 9-16         Speed Bit 1-8
   Variable
The speed value is of int32 type, and the range -100000 to 100000 represents -100000 to 100000
electrical RPM.
Velocity Loop Send Example Routine

void comm_can_set_rpm(uint8_t controller_id, float rpm) {
     int32_t send_index = 0;
     uint8_t buffer[4];
     buffer_append_int32(buffer, (int32_t)rpm, &send_index);
     comm_can_transmit_eid(controller_id |
                    ((uint32_t)CAN_PACKET_SET_RPM << 8), buffer, send_index);
}

4.1.5 Position Loop Mode
Simplified Control Diagram for Position Loop

Position Loop Mode Data Transmission Definition
    Data Bit                   Data[0]              Data[1]             Data[2]               Data[3]
      Range                    0~0xff               0~0xff               0~0xff                0~0xff
 Corresponding variable   Position Bit 25-32   Position Bit 17-24   Position Bit 9-16     Position Bit 1-8

                                                      35 / 54
                                                                                   E-mail:info@cubemars.com
                                                                                  https://www.cubemars.com/

The position value is of int32 type, and the range -360000000 to 360000000 represents positions
from -36000° to 36000°.
Position Loop Send Example Routine

void comm_can_set_pos(uint8_t controller_id, float pos) {
     int32_t send_index = 0;
     uint8_t buffer[4];
     buffer_append_int32(buffer, (int32_t)(pos * 10000.0), &send_index);
     comm_can_transmit_eid(controller_id |
               ((uint32_t)CAN_PACKET_SET_POS << 8), buffer, send_index);
}

4.1.6 Setting Origin Mode

   Data Bit           Data[0]

    Range             0~0x01

Corresponding
                   Set Command
   Variable
The set command is of uint8_t type, 0 represents setting a temporary origin (erased upon power
loss), and 1 represents setting a permanent origin (parameters are automatically saved).

Position Loop Send Example Routine

void comm_can_set_origin(uint8_t controller_id, uint8_t set_origin_mode) {
     int32_t send_index = 1;
     uint8_t buffer;
     buffer=set_origin_mode;
     comm_can_transmit_eid(controller_id |
               ((uint32_t) CAN_PACKET_SET_ORIGIN_HERE << 8), buffer, send_index);
}

                                            36 / 54
                                                                       E-mail:info@cubemars.com
                                                                      https://www.cubemars.com/

        4.1.7 Position-Velocity Loop Mode
        Simplified Diagram for Position-Speed Loop

        Position-Velocity Loop Mode Data Transmission Definition

Data Bit          Data[0]    Data[1]       Data[2]    Data[3]    Data[4]   Data[5]   Data[6]        Data[7]

Range             0~0xff     0~0xff        0~0xff     0~0xff     0~0xff    0~0xff    0~0xff         0~0xff

Corresponding     Position   Position      Position   Position   Speed     Speed     Acceleration   Acceleration
Variable          25-32      17-24         9-16       1-8        High      Low       High Byte      Low Byte
                                                                 Byte      Byte
        The position value is of int32 type, and the range -360000000 to 360000000 corresponds to
        positions from -36000° to 36000

        The speed value is of int16 type, and the range -32768 to 32767 corresponds to -327680 to
        327680 ERPM;

        The acceleration value is of int16 type, and the range 0 to 32767 corresponds to 0 to 327670,
        with 1 unit equal to 10 ERPM/s².

        void comm_can_set_pos_spd(uint8_t controller_id, float pos,int16_t spd, int16_t RPA ) {
             int32_t send_index = 0;
             Int16_t send_index1 = 4;
             uint8_t buffer[8];
             buffer_append_int32(buffer, (int32_t)(pos * 10000.0), &send_index);
             buffer_append_int16(buffer,spd/10.0, & send_index1);
             buffer_append_int16(buffer,RPA/10.0, & send_index1);
             comm_can_transmit_eid(controller_id |
                       ((uint32_t)CAN_PACKET_SET_POS_SPD << 8), buffer, send_index1);
        }

        4.2 Force Control Mode (MIT) Communication Protocol
        The MIT Control Mode has three control modes, all sharing a single Control ID number, with the
        specific control mode determined by the transmitted data. For detailed operation of each mode
        on the upper computer, see section 3.3.2.

                                                       37 / 54
                                                                                 E-mail:info@cubemars.com
                                                                                https://www.cubemars.com/

    Position Loop Mode: Operates the motor with a specified position and Kp, Kd values, the motor
    is going to rotate to the specified position.
    Velocity Loop Mode: Operates the motor with a specified speed and Kd value, the motor is going
    to rotate at the specified speed.
    Current Loop Mode: Operates the motor with a specified torque value, the motor is going to
    rotate at the specified torque value.

    The Force Control Mode uses the CAN protocol, adopting an extended frame format as shown
    below
    Can ID bits                [28]-[8]                            [7]-[0]
    Field name                 Control mode ID                     Drive ID
    The Control Mode ID for the Force Control Mode has a characteristic value of 8

    Force Control Mode Driver Board Data Transmission Definition
    Identifier: Control Mode ID + Driver ID     Frame Type: Extended Frame
    Frame Format: DATA                            DLC: 8 bytes
  Data            DATA[0]                   DATA[1]                     DATA[2]             DATA[3]
  Field
Data Bits           7-0              7-4               3-0                7-0                 7-0
 Data        High 8 bits of   Low 4 bits of KP    High 4 bits of    Low 8 bits of        High 8 bits of
Content        KP value           value             KD value          KD value           Position value

  Data            DATA[4]         DATA[5]                     DATA[6]                       DATA[7]
  Field
Data Bits           7-0              7-0               7-4                3-0                 0-7
 Data        Low 8 bits of      High 8 bits of    High 8 bits of    High 4 bits of       Low 8 bits of
Content      Position value     Speed value       Speed value       Current value        Current value

    Simplified Diagram for Force Control Mode

                                                 38 / 54
                                                                               E-mail:info@cubemars.com
                                                                              https://www.cubemars.com/

Parameter Ranges
       Module        AK10-9       AK60-6       AK70-9           AK80-9      AKE60-8      AKE80-8
        Motor
          KV            60          80           60               100          80           30
        Motor
       position                                   -12.56f-12.56f
        (rad)
     Motor speed    -28.0f-28.   -60.0f-60.   -30.0f-30.       -65.0f-65.   -40.0f-40.   -20.0f-20.
      （rad/s）           0f              0f       0f               0f           0f           0f
        Motor
                    -54.0f-54.   -12.0f-12.   -32.0f-32.       -18.0f-18.   -15.0f-15.   -35.0f-35.
        torque
                        0f              0f       0f               0f           0f           0f
      （N.M）

       Kp range                                         0-500

       Kd range                                          0-5

  Force Control Mode Send Code Example
(AK10-9 as an example)
u8 SERVO_Can_Send_Msg(uint32_t ExtId,u8* msg,u8 len)
{
          u8 mbox;
          u16 i=0;
//              TxMessage.StdId=stdId;         // standard identifier
          TxMessage.ExtId=ExtId;          // Setting the Extended Marker
          TxMessage.IDE=CAN_Id_Extended;       // standard frame
          TxMessage.RTR=CAN_RTR_Data;          // data frame
          TxMessage.DLC=len;                   // Length of data to be sent
          for(i=0;i<len;i++)
          TxMessage.Data[i]=msg[i];
          mbox= CAN_Transmit(CANx, &TxMessage);
          i=0;
          while((CAN_TransmitStatus(CAN1,       mbox)==CAN_TxStatus_Failed)&&(i<0XFFF))i++;
     //Waiting for the end of sending
          if(i>=0XFFF)return 1;
          return 0;
}

float fmaxf(float x, float y){
      /// Returns maximum of x, y ///
      return (((x)>(y))?(x):(y));
      }
                                              39 / 54
                                                                               E-mail:info@cubemars.com
                                                                              https://www.cubemars.com/

float fminf(float x, float y){
      /// Returns minimum of x, y ///
      return (((x)<(y))?(x):(y));
      }

float fmaxf3(float x, float y, float z){
      /// Returns maximum of x, y, z ///
      return (x > y ? (x > z ? x : z) : (y > z ? y : z));
      }

float fminf3(float x, float y, float z){
      /// Returns minimum of x, y, z ///
      return (x < y ? (x < z ? x : z) : (y < z ? y : z));
      }

float P_MIN =-12.56f;
float P_MAX =12.56f;
float V_MIN =-28.0f;
float V_MAX =28.0f;
float T_MIN =-54.0f;
float T_MAX =54.0f;
float Kp_MIN =0;
float Kp_MAX =500.0f;
float Kd_MIN =0;
float Kd_MAX =5.0f;
float Test_Pos=0.0f;

int p_int ;
int v_int ;
int kp_int ;
int kd_int ;
int t_int ;

void pack_cmd(uint8_t controller_id, float p_des, float v_des, float kp, float kd, float t_ff){
uint8_t buffer[8];

p_des = fminf(fmaxf(P_MIN, 0), P_MAX);
v_des = fminf(fmaxf(V_MIN, 0), V_MAX);
kp = fminf(fmaxf(Kp_MIN, kp), Kp_MAX);

                                                        40 / 54
                                                                             E-mail:info@cubemars.com
                                                                            https://www.cubemars.com/

kd = fminf(fmaxf(Kd_MIN, kd), Kd_MAX);
t_ff = fminf(fmaxf(T_MIN, t_ff), T_MAX);
/// convert floats to unsigned ints ///

 p_int = float_to_uint(p_des, P_MIN, P_MAX, 16);
 v_int = float_to_uint(v_des, V_MIN, V_MAX, 12);
 kp_int = float_to_uint(kp, Kp_MIN, Kp_MAX, 12);
 kd_int = float_to_uint(kd, Kd_MIN, Kd_MAX, 12);
 t_int = float_to_uint(t_ff, T_MIN, T_MAX, 12);

/// pack ints into the can buffer ///
buffer[0] = kp_int>>4;         //KP high 8 bits
buffer[1] = ((kp_int&0xF)<<4)|( kd_int>>8); //KP Low 4 bits, Kd High 4 bits
buffer[2] = kd_int&0xFF;       //Kd low 8 bits
buffer[3] = p_int>>8;             //position high 8 bits
buffer[4] = p_int&0xFF; //position low 8 bits
buffer[5] = v_int>>4;     //speed high 8 bits
buffer[6] = ((v_int&0xF)<<4)|(t_int>>8);       //speed low 4 bits torque high 4 bits
buffer[7] = t_int&0xff; //torque low 8 bits
SERVO_Can_Send_Msg(controller_id |((uint32_t) CAN_PACKET_SET_mit << 8), buffer, 8);
       }

When sending data, all numbers must be converted to integers through the

following function before being sent to the motor.

       int float_to_uint(float x, float x_min, float x_max, unsigned int bits){
             /// Converts a float to an unsigned int, given range and number of bits ///
             float span = x_max - x_min;
             if(x < x_min) x = x_min;
             else if(x > x_max) x = x_max;
             return (int) ((x- x_min)*((float)((1<<bits)/span)));
       }

                                               41 / 54
                                                                           E-mail:info@cubemars.com
                                                                          https://www.cubemars.com/

        4.3 Motor Message Format

        4.3.1 CAN Upload Message Protocol
        The motor CAN message uses a timed upload mode, with an upload frequency that can be set
        from 1 to 500 Hz, and the upload byte is 8 bytes.

Data Bit           Data[0]    Data[1]    Data[2]    Data[3]     Data[4]    Data[5]       Data[6]         Data[7]

Range              0~0xff     0~0xff     0~0xff     0~0xff      0~0xff     0~0xff        0~0xff          0~0xff

Corresponding      High       Low        High       Low         High       Low           Motor           Error
Variable           Byte of    Byte of    Byte of    Byte of     Byte of    Byte of       Temperature     Code
                   Position   Position   Speed      Speed       Current    Current

        The position is of int16 type, with a range of -32000 to 32000 representing a position of -3200°
        to 3200°;
        The speed is of int16 type, with a range of -32000 to 32000 representing an electrical speed of
        -320000 to 320000 rpm;
        The current is of int16 type, with values -6000 to 6000 representing -60 to 60 A;
        The temperature is of int8 type, with a range of -20 to 127 representing the driver board
        temperature of -20°C to 127°C;
        The error code is of uint8 type, with 0 indicating no fault, 1 indicating motor over-temperature
        fault, 2 indicating over-current fault, 3 indicating over-voltage fault, 4 indicating under-voltage
        fault, 5 indicating encoder fault, 6 indicating MOSFET over-temperature fault, and 7 indicating
        motor lock-up.

        Below is an example of message reception

        void motor_receive(float* motor_pos,float*
        motor_spd,float* cur,int_8* temp,int_8* error,rx_message)
          {
              int16_t pos_int = (rx_message)->Data[0] << 8 | (rx_message)->Data[1]);
              int16_t spd_int = (rx_message)->Data[2] << 8 | (rx_message)->Data[3]);
              int16_t cur_int = (rx_message)->Data[4] << 8 | (rx_message)->Data[5]);
             &motor_pos= (float)( pos_int * 0.1f); //Motor position
             &motor_spd= (float)( spd_int * 10.0f);//Motor speed
             &motor_cur= (float) ( cur_int * 0.01f);//Motor current
             &motor_temp= (rx_message)->Data[6] ;//Motor temperature
             &motor_error= (rx_message)->Data[7] ;//Motor error code
          }

                                                      42 / 54
                                                                                     E-mail:info@cubemars.com
                                                                                    https://www.cubemars.com/

4.3.2 Serial Port Message Protocol
The serial port's send and receive message protocol is as follows:

FrameHeader     Data           Data          Data Bit      Checksum    Checksum     FrameTail
  （0xAA）        Length         Frame                       High byte   Low byte       （0xBB）
                (excluding
                frame
                header,
                frame tail,
                checksum)
For the calculation of the checksum, refer to section 4.3.2.2.

Data Frame Definition
typedef enum {
     COMM_FW_VERSION = 65,
     COMM_JUMP_TO_BOOTLOADER=66,
     COMM_ERASE_NEW_APP=67,
     COMM_WRITE_NEW_APP_DATA=68,
     COMM_GET_VALUES=69,     //Get motor operating parameters
     COMM_SET_DUTY=70,       //The motor operates in duty cycle mode
     COMM_SET_CURRENT=71, //The motor operates in current loop mode
     COMM_SET_CURRENT_BRAKE=72, //The motor operates in current bake mode
     COMM_SET_RPM=73,            //The motor operates in velocity loop mode
     COMM_SET_POS=74,           //The motor operates in position loop mode
     COMM_SET_HANDBRAKE=75,     //The motor operates om handbrake current loop mode
     COMM_SET_DETECT=76,          //The motor provides real-time feedback on the current
position command
     COMM_ROTOR_POSITION=87,//The motor feedbacks the current position
     COMM_GET_VALUES_SETUP=16,//The motor requires instructions based on one or more
parameters
     COMM_SET_POS_SPD=60,      // The motor operates in position-velocity loop mode
     COMM_SET_POS_MULTI=61,    //Set the motor movement to single circle motion mode
     COMM_SET_POS_SINGLE=62, // Set the motor movement to multiple circles motion mode,
range±100
     COMM_SET_POS_UNLIMITED=63, //Save
     COMM_SET_POS_ORIGIN=64, //Set the motor’s origin
} COMM_PACKET_ID;

                                               43 / 54
                                                                         E-mail:info@cubemars.com
                                                                        https://www.cubemars.com/

4.3.2.1 Get the parameters
1. Get the motor parameters
Serial port command：
AA 01 45 18 61 BB
Respond:
AA 49 45 01 27 FC DF 00 00 00 00 00 00 00 00 00 00 00 00 00 00 00 00 00 00 00 00 00 00 00 F2
00 00 00 00 00 00 00 00 00 00 00 00 00 00 00 00 FF FF FF FD 00 00 00 07 00 FF EF 54 F1 68 00 00
00 00 00 00 00 00 00 00 FF FF FF FC 86 D5 BB
Clarification:
Get the motor parameters and feedback the motor status once after the motor receives it.
Parameter parsing:
 AA (frame header) + 55 (data length) + 45 (data frame) + mos temperature (2byte) + motor
temperature (2byte) + output current (4byte) + input current (4byte) + Id current (4byte) + Iq
current (4byte) + motor throttle value (2byte) + motor speed (4byte) + input voltage ( 2byte) +
Reserved Value (24byte) + Motor Status Code (1byte) + Motor Outer Loop Position Value (4byte)
+ Motor Control ID Number (1byte) + Temperature Reserved Value (6byte) + Vd Voltage Value
(4byte) + Vq Voltage Value (4byte) + Current Control Mode (4byte) + Encoder Angle (4byte) +
Outer Encoder angle (4byte) + CRC + BB (end of frame)

The formulas for converting some of the parameters sent by the motor are as
follows:
MOS temperature = (float)buffer_get_int16(data, &ind) / 10.0)
Motor temperature = (float)buffer_get_int16(data, &ind) / 10.0)
Output current = (float)buffer_get_int32(data, &ind) / 100.0)
Input current = (float)buffer_get_int32(data, &ind) / 100.0)
Id current = (float)buffer_get_int32(data, &ind) / 100.0)
Iq current = (float)buffer_get_int32(data, &ind) / 100.0)
Duty cycle value = (float)buffer_get_int16(data, &ind) / 1000.0)
Motor speed = (float)buffer_get_int32(data, &ind) )
Input voltage = (float)buffer_get_int16(data, &ind) / 10.0)
Motor outer loop position = (float)buffer_get_float (data, &ind))
Motor ID number = data
Motor Vd voltage = (float)buffer_get_int32 (data, &ind) / 1000.0)
Motor Vq voltage = (float)buffer_get_int32(data, &ind) / 1000.0)
Encoder angle = (float)buffer_get_float (data, &ind))
outer encoder angle = (float)buffer_get_float (data, &ind))

2.Get the motor’s position
Command:
AA 02 4C 04 08 25 BB
Respond:
AA 05 57 00 1A B6 64 6E CD BB
                                              44 / 54
                                                                       E-mail:info@cubemars.com
                                                                      https://www.cubemars.com/

             Clarification:
             Motor receives and sends current position every 10ms.
             Parameter parsing:
             Pos=(float)buffer_get_float (data, &ind))

             3.Get single or multiple parameters of the motor
             Command:
             AA 05 13 00 00 00 01 FA A9 BB    //Get MOS temperature
             Respond:
             AA 07 13 00 00 00 01 01 21 DF BB BB // Feedback motor temperature
             Clarification:
             Get single or multiple motor parameters, the parameters are determined by the 4-byte bits in the
             command data field, when the corresponding bit is 1, the motor will return the motor
             parameters of the corresponding bit, and when it is 0, the field is removed (the order of getting
             the motor parameters starts from the first bit).
             The motor parameters corresponding to the bits are listed in the table below:

32-19 Bit     18 Bit         17 Bit          16 Bit              10-15 Bit      9 Bit            8 Bit              7 Bit

              Motor ID       Motor pos       Motor error                      Input voltage      Motor speed        Duty cycle
Reserved                                                        Reserved
              1byte          4byte           1byte                            2byte              4byte              2byte
6 Bit         5 Bit          4 Bit           3 Bit              2 Bit         1 Bit
Iq current    Id current     Input current   Output current     Motor temp    MOS temp
4byte         4byte          4byte           4byte              2byte         2byte

             After the motor receives this command, it will send the corresponding parameters.
             Example: AA 07 13 00 00 00 01 01 21 DF BB BB // Feedback motor temperature
             The formulas for converting some of the parameters sent by the motor are as follows:
             MOS temperature = (float)buffer_get_int16(data, &ind) / 10.0
             Motor temperature = (float)buffer_get_int16(data, &ind) / 10.0
             Output current = (float)buffer_get_int32(data, &ind) / 100.0
             Input current = (float)buffer_get_int32(data, &ind) / 100.0
             Motor throttle value = (float)buffer_get_int16(data, &ind) / 1000.0
             Motor speed = (float)buffer_get_int32(data, &ind)
             Input voltage = (float)buffer_get_int16(data, &ind) / 10.0
             Motor position = (float)buffer_get_int32(data, &ind) / 1000000.0
             Motor ID number = data

             Motor error status code

             typedef enum {
                 FAULT_CODE_NONE = 0,
                 FAULT_CODE_OVER_VOLTAGE,// Over-voltage
                                                           45 / 54
                                                                                         E-mail:info@cubemars.com
                                                                                        https://www.cubemars.com/

    FAULT_CODE_UNDER_VOLTAGE,// Under-voltage
    FAULT_CODE_DRV,// Drive fault
    FAULT_CODE_ABS_OVER_CURRENT,// Motor over-current
    FAULT_CODE_OVER_TEMP_FET,// MOS over-temperature
    FAULT_CODE_OVER_TEMP_MOTOR,// Motor over-temperature
    FAULT_CODE_GATE_DRIVER_OVER_VOLTAGE,// Drive over voltage
    FAULT_CODE_GATE_DRIVER_UNDER_VOLTAGE,// Drive undervoltage
    FAULT_CODE_MCU_UNDER_VOLTAGE,// MCU under-voltage
    FAULT_CODE_BOOTING_FROM_WATCHDOG_RESET,// Under voltage
    FAULT_CODE_ENCODER_SPI,// SPI Encoder fault
    FAULT_CODE_ENCODER_SINCOS_BELOW_MIN_AMPLITUDE,//Encoder        limit    exceeded
      FAULT_CODE_ENCODER_SINCOS_ABOVE_MAX_AMPLITUDE,//Encoder limit exceeded
    FAULT_CODE_FLASH_CORRUPTION,// FLASH Gault
    FAULT_CODE_HIGH_OFFSET_CURRENT_SENSOR_1,// Curretnt sampling channel 1 fault
    FAULT_CODE_HIGH_OFFSET_CURRENT_SENSOR_2,// Curretnt sampling channel 2 fault
    FAULT_CODE_HIGH_OFFSET_CURRENT_SENSOR_3,// Curretnt sampling channel 3 fault
    FAULT_CODE_UNBALANCED_CURRENTS,// Current imbalance

} mc_fault_code;

4.3.2.2 Control commands

1.Duty Cycle Transmit Mode

Command:
    AA 05 46 00 00 4E 20 D6 4C BB          // 0.20 duty cycle
    AA 05 46 FF FF B1 E0 88 3F BB          // -0.20 duty cycle

Parameters parsing:

Duty=(float)buffer_get_int32(data, &ind) / 100000.0)     //The value is to receive 4 bits of
data/100000.0

2.Current Loop Transmit Mode

Command:
    AA 05 47 00 00 13 88 30 1C BB          //5 A IQ current
    AA 05 47 FF FF EC 78 58 3C BB          //-5 A IQ current

Parameters parsing:

Current=(float)buffer_get_int32(data, &ind) / 1000.0     //The value is to receive 4 bits of
data/1000.0

3.Brake Loop Current Transmit Mode

Command:
                                             46 / 54
                                                                         E-mail:info@cubemars.com
                                                                        https://www.cubemars.com/

    AA 05 48 00 00 13 88 55 E5 BB          //5A brake current
    AA 05 48 FF FF EC 78 3D C5 BB          //- 5A brake current

Parameters parsing:
     I_Brake=(float)buffer_get_int32(data, &ind) / 1000.0      //The value is to receive 4 bits of
data/1000.0

4.Velocity Loop Transmit Mode

Command:
    AA 05 49 00 00 03 E8 90 61 BB          // 1000 ERPM
    AA 05 49 FF FF FC 18 F8 41 BB          // - 1000 ERPM

Parameters parsing:
    Speed=(float)buffer_get_int32(data, &ind)      //The value is to receive 4 bits of data

5.Position Loop Transmit Mode

Command:
    AA 05 4A 0A BA 95 00 E1 4D BB          //motor rotates to 180º
    AA 05 4A 05 5D 4A 80 84 93 BB          //motor rotates to 90º

Parameters parsing:
Pos=(float)buffer_get_int32(data, &ind) / 1000000.0     //The value is to receive 4 bits of data
/1000000.0

6.Handbrake Current Transmit Mode

Command:
    AA 05 48 00 00 13 88 55 E5 BB          //5A HB Current ERPM
    AA 05 48 FF FF EC 78 3D C5 BB          //-5A HB Current ERPM

Parameters parsing:
HAND_Brake=(float)buffer_get_int32(data, &ind) / 1000.0        //The value is to receive 4 bits of
data/1000.0

7.Position-velocity Loop Transmit Mode

Command:
    AA 0D 3C 00 02 BF 20 00 00 13 88 00 00 75 30 18 1C BB

Parameters parsing:
position+ velocity + acceleration
     180 degree rpm 5000ERPM acceleration 30000/S
Pos=(float)buffer_get_int32(data, &ind) / 1000.0) //The value is to receive 4 bits of
data/1000.0

                                             47 / 54
                                                                         E-mail:info@cubemars.com
                                                                        https://www.cubemars.com/

Speed=(float)buffer_get_int32(data, &ind)
     //vAcc_Speed=(float)buffer_get_int32(data, &ind)            //The value is to receive 4 bits of
data

8.MIT Transmit Mode

Command:
     AA 15 60 00 00 00 00 00 00 17 70 00 00 00 00 00 00 00 00 00 00 07 D0 93 DA BB
     //Kd set 2，speed set to 6rad/s
     AA 15 60 00 00 00 00 FF FF E8 90 00 00 00 00 00 00 00 00 00 00 07 D0 87 5C BB
     //Kd set 2，speed set to -6rad/s

Parameters parsing:
Position + Velocity + Current + KP + KD
     Pos=(float)buffer_get_int32(data, &ind) / 1000.0)     //The value is to receive 4 bits of data
/1000.0
Speed=(float)buffer_get_int32(data, &ind / 1000.0) //The value is to receive 4 bits of data
     /1000.0
Current=(float)buffer_get_int32(data, &ind / 1000.0) //The value is to receive 4 bits of data
     /1000.0
KP=(float)buffer_get_int32(data, &ind / 1000.0)        //The value is to receive 4 bits of data
     /1000.0
KD=(float)buffer_get_int32(data, &ind / 1000.0)        //The value is to receive 4 bits of data
     /1000.0

Data Transformation:
int16_t buffer_get_int16(uint8_t* buffer, int32_t *index)
{
     Int16_t res = ((uint16_t)buffer[*index])<<8|
                     ((uint16_t)buffer[*index+1]);
     return res;
}

uint16_t buffer_get_int16(uint8_t* buffer, int32_t *index)
{
     Uint16_t res = ((uint16_t)buffer[*index])<<8|
                    ((uint16_t)buffer[*index+1]);
     return res;
}

int32_t buffer_get_int32(uint8_t* buffer, int32_t *index)
{
     int32_t res = ((uint32_t)buffer[*index])<<24|
                     ((uint32_t)buffer[*index+1])<<16|

                                               48 / 54
                                                                           E-mail:info@cubemars.com
                                                                          https://www.cubemars.com/

                    ((uint32_t)buffer[*index+2])<<8|
                    ((uint32_t)buffer[*index+3]);
     return res;
}

uint32_t buffer_get_uint32(uint8_t* buffer, int32_t *index)
{
     uint32_t res = ((uint32_t)buffer[*index])<<24|
                     ((uint32_t)buffer[*index+1])<<16|
                     ((uint32_t)buffer[*index+2])<<8|
                     ((uint32_t)buffer[*index+3]);
     return res;
}

float buffer_get_float(uint8_t* buffer, int32_t *index)
{
    float *res;
    uint32_t data;
    data = buffer_get_uint32(buffer,index);
    res = (float*)&data;
    return *res;
}

//int16 Data Bit Collation
void buffer_append_int16(uint8_t* buffer, int16_t number, int32_t *index) {
          buffer[(*index)++] = number >> 8;
          buffer[(*index)++] = number;
     }

//uint16 Data Bit Collation
void buffer_append_uint16(uint8_t* buffer, uint16_t number, int32_t *index) {
          buffer[(*index)++] = number >> 8;
          buffer[(*index)++] = number;
     }

//int32 Data Bit Collation
void buffer_append_int32(uint8_t* buffer, int32_t number, int32_t *index) {
          buffer[(*index)++] = number >> 24;
          buffer[(*index)++] = number >> 16;
          buffer[(*index)++] = number >> 8;
          buffer[(*index)++] = number;
     }

                                               49 / 54
                                                                        E-mail:info@cubemars.com
                                                                       https://www.cubemars.com/

//uint32 Data Bit Collation
void buffer_append_uint32(uint8_t* buffer, uint32_t number, int32_t *index) {
          buffer[(*index)++] = number >> 24;
          buffer[(*index)++] = number >> 16;
          buffer[(*index)++] = number >> 8;
          buffer[(*index)++] = number;
     }
}

4.3.2.3 serial port calibration
const unsigned short crc16_tab[] = { 0x0000, 0x1021, 0x2042, 0x3063, 0x4084,
0x50a5, 0x60c6, 0x70e7, 0x8108, 0x9129, 0xa14a, 0xb16b, 0xc18c, 0xd1ad,
0xe1ce, 0xf1ef, 0x1231, 0x0210, 0x3273, 0x2252, 0x52b5, 0x4294, 0x72f7,
0x62d6, 0x9339, 0x8318, 0xb37b, 0xa35a, 0xd3bd, 0xc39c, 0xf3ff, 0xe3de,
0x2462, 0x3443, 0x0420, 0x1401, 0x64e6, 0x74c7, 0x44a4, 0x5485, 0xa56a,
0xb54b, 0x8528, 0x9509, 0xe5ee, 0xf5cf, 0xc5ac, 0xd58d, 0x3653, 0x2672,
0x1611, 0x0630, 0x76d7, 0x66f6, 0x5695, 0x46b4, 0xb75b, 0xa77a, 0x9719,
0x8738, 0xf7df, 0xe7fe, 0xd79d, 0xc7bc, 0x48c4, 0x58e5, 0x6886, 0x78a7,
0x0840, 0x1861, 0x2802, 0x3823, 0xc9cc, 0xd9ed, 0xe98e, 0xf9af, 0x8948,
0x9969, 0xa90a, 0xb92b, 0x5af5, 0x4ad4, 0x7ab7, 0x6a96, 0x1a71, 0x0a50,
0x3a33, 0x2a12, 0xdbfd, 0xcbdc, 0xfbbf, 0xeb9e, 0x9b79, 0x8b58, 0xbb3b,
0xab1a, 0x6ca6, 0x7c87, 0x4ce4, 0x5cc5, 0x2c22, 0x3c03, 0x0c60, 0x1c41,
0xedae, 0xfd8f, 0xcdec, 0xddcd, 0xad2a, 0xbd0b, 0x8d68, 0x9d49, 0x7e97,
0x6eb6, 0x5ed5, 0x4ef4, 0x3e13, 0x2e32, 0x1e51, 0x0e70, 0xff9f, 0xefbe,
0xdfdd, 0xcffc, 0xbf1b, 0xaf3a, 0x9f59, 0x8f78, 0x9188, 0x81a9, 0xb1ca,
0xa1eb, 0xd10c, 0xc12d, 0xf14e, 0xe16f, 0x1080, 0x00a1, 0x30c2, 0x20e3,
0x5004, 0x4025, 0x7046, 0x6067, 0x83b9, 0x9398, 0xa3fb, 0xb3da, 0xc33d,
0xd31c, 0xe37f, 0xf35e, 0x02b1, 0x1290, 0x22f3, 0x32d2, 0x4235, 0x5214,
0x6277, 0x7256, 0xb5ea, 0xa5cb, 0x95a8, 0x8589, 0xf56e, 0xe54f, 0xd52c,
0xc50d, 0x34e2, 0x24c3, 0x14a0, 0x0481, 0x7466, 0x6447, 0x5424, 0x4405,
0xa7db, 0xb7fa, 0x8799, 0x97b8, 0xe75f, 0xf77e, 0xc71d, 0xd73c, 0x26d3,
0x36f2, 0x0691, 0x16b0, 0x6657, 0x7676, 0x4615, 0x5634, 0xd94c, 0xc96d,
0xf90e, 0xe92f, 0x99c8, 0x89e9, 0xb98a, 0xa9ab, 0x5844, 0x4865, 0x7806,
0x6827, 0x18c0, 0x08e1, 0x3882, 0x28a3, 0xcb7d, 0xdb5c, 0xeb3f, 0xfb1e,
0x8bf9, 0x9bd8, 0xabbb, 0xbb9a, 0x4a75, 0x5a54, 0x6a37, 0x7a16, 0x0af1,
0x1ad0, 0x2ab3, 0x3a92, 0xfd2e, 0xed0f, 0xdd6c, 0xcd4d, 0xbdaa, 0xad8b,
0x9de8, 0x8dc9, 0x7c26, 0x6c07, 0x5c64, 0x4c45, 0x3ca2, 0x2c83, 0x1ce0,
0x0cc1, 0xef1f, 0xff3e, 0xcf5d, 0xdf7c, 0xaf9b, 0xbfba, 0x8fd9, 0x9ff8,
0x6e17, 0x7e36, 0x4e55, 0x5e74, 0x2e93, 0x3eb2, 0x0ed1, 0x1ef0 };

//CRC checksum
unsigned short crc16(unsigned char *buf, unsigned int len) {
     unsigned int i;
     unsigned short cksum = 0;
                                              50 / 54
                                                                        E-mail:info@cubemars.com
                                                                       https://www.cubemars.com/

    for (i = 0; i < len; i++) {
          cksum = crc16_tab[(((cksum >> 8) ^ *buf++) & 0xFF)] ^ (cksum << 8);
    }
    return cksum;
}

//Packet collation for sending
void packet_send_packet(unsigned char *data, unsigned int len, int handler_num) {
     int b_ind = 0;
     unsigned short crc;
     if (len > PACKET_MAX_PL_LEN) {
           return;
     }
     if (len <= 256) {
           handler_states[handler_num].tx_buffer[b_ind++] = 0xAA;
           handler_states[handler_num].tx_buffer[b_ind++] = len;
     } else {
           handler_states[handler_num].tx_buffer[b_ind++] = 0xAB;
           handler_states[handler_num].tx_buffer[b_ind++] = len >> 8;
           handler_states[handler_num].tx_buffer[b_ind++] = len & 0xFF;
     }

    memcpy(handler_states[handler_num].tx_buffer + b_ind, data, len);
    b_ind += len;

    crc = crc16(data, len);
    handler_states[handler_num].tx_buffer[b_ind++] = (uint8_t)(crc >> 8);
    handler_states[handler_num].tx_buffer[b_ind++] = (uint8_t)(crc & 0xFF);
    handler_states[handler_num].tx_buffer[b_ind++] = 0xBB;

    if (handler_states[handler_num].send_func) {
          handler_states[handler_num].send_func(handler_states[handler_num].tx_buffer,
b_ind);
    }
}

                                             51 / 54
                                                                        E-mail:info@cubemars.com
                                                                       https://www.cubemars.com/

4.4 Control Command Examples

4.4.1 CAN Port Control Command Examples
Frame format: Extended frame - Data frame (using motor ID 0x68 as an example)

        Mode                  ID                      DATA                Descriptions

                         00 00 00 68            00 00 4E 20         0.2 Duty Cycle
   Duty Cycle Mode
                         00 00 00 68             FF FF B1 E0        -0.2 Duty Cycle

                         00 00 01 68             FF FF F0 60        -4A IQ Current
     Current Loop
                         00 00 01 68            00 00 0F A0         4A IQ Current

    Brake Current        00 00 02 68             FF FF F0 60        -4A Brake current
        Mode
                         00 00 02 68            00 00 0F A0         4A Brake current
                                                                    5000 ERPM Electrical
                         00 00 03 68            00 00 13 88
                                                                    Speed
     Velocity Loop
                                                                    -5000 ERPM Electrical
                         00 00 03 68             FF FF EC 78
                                                                    Speed
                                                                    Motor rotates to
                         00 00 04 68            00 5B 8D 80
                                                                    600degrees
     Position Loop
                                                                    Motor rotates to
                         00 00 04 68            FF A4 72 80
                                                                    -600degrees
                                                                    Motor rotates to
                                                                    1000degrees
                                                                    10000 ERPM electrical
                         00 00 06 68      00 98 96 80 03 E8 03 E8
                                                                    speed
                                                                    10000 electrical
   Position-Velocity                                                acceleration
         Loop                                                       Motor rotates to
                                                                    -1000degrees
                                                                    -10000 ERPM electrical
                         00 00 06 68      FF 67 69 80 FC 18 FC 18
                                                                    speed
                                                                    -10000 electrical
                                                                    acceleration
                                                                     Kd set to 2, speed set
                         00 00 08 68      00 06 66 7F FF 8F 57 FF
                                                                    to 6rad/s
   MIT Velocity Loop
                                                                    Kd set to 2, speed set to
                         00 00 08 68      00 06 66 7F FF 70 97 FF
                                                                    -6rad/s

                                            52 / 54
                                                                       E-mail:info@cubemars.com
                                                                      https://www.cubemars.com/

                                                                      Kp set to 2, Kd set to 2,
                          00 00 08 68      01 06 66 BD 70 7F F7 FF
                                                                      motor rotates to 6rad
  MIT Position Loop                                                   Kp set to 2, Kd set to 2,
                          00 00 08 68      01 06 66 42 8F 7F F7 FF    motor rotates to -6rad

                          00 00 08 68      00 00 00 7F FF 7F F8 3F    2A IQ Current
   MIT Torque Loop
                          00 00 08 68      00 00 00 7F FF 7F F8 7E    4A IQ Current

4.4.2 Serial Port Control Command Examples
        Mode                      Serial Port Command                       Descriptions
                                                                      0.20 Duty Cycle
                              AA 05 46 00 00 4E 20 D6 4C BB
  Duty Cycle Mode
                                                                      -0.20 Duty Cycle
                              AA 05 46 FF FF B1 E0 88 3F BB

                              AA 05 48 00 00 13 88 55 E5 BB
                                                                      5A Brake Current
    Brake Current
        Mode                  AA 05 48 FF FF EC 78 3D C5 BB
                                                                      -5A Brake Current

                                                                      1000 ERPM Electrical
                              AA 05 49 00 00 03 E8 90 61 BB
                                                                      Speed
    Velocity Loop
                              AA 05 49 FF FF FC 18 F8 41 BB           -1000 ERPM Electrical
                                                                      Speed
                             AA 05 4A 0A BA 95 00 E1 4D BB            Motor rotates to 180
                                                                      degrees
    Position Loop                                                     Motor rotates to 90
                              AA 05 4A 05 5D 4A 80 84 93 BB
                                                                      degrees

                                                                      180 degrees, speed
                       AA 0D 3C 00 02 BF 20 00 00 13 88 00 00 75 30
   Position-Velocity                                                  5000ERPM,
                                        18 1C BB
         Loop                                                         acceleration 30000/S

                              AA 05 47 00 00 13 88 30 1C BB           5 A IQ Current

    Current Loop
                              AA 05 47 FF FF EC 78 58 3C BB           -5A    IQ Current

                       AA 15 60 00 00 00 00 00 00 17 70 00 00 00 00   Kd set to 2, speed set to
  MIT Velocity Loop
                             00 00 00 00 00 00 07 D0 93 DA BB         6rad/s

                                             53 / 54
                                                                         E-mail:info@cubemars.com
                                                                        https://www.cubemars.com/

                    AA 15 60 00 00 00 00 FF FF E8 90 00 00 00 00   Kd set to2, speed set to
                         00 00 00 00 00 00 07 D0 87 5C BB          -6rad/s
                                                                   Kp set to 2, Kd set to 2,
                    AA 15 60 00 00 17 70 00 00 00 64 00 00 00 00
                                                                   motor rotates to 6rad
                         00 00 07 D0 00 00 07 D0 91 BC BB
MIT Position Loop
                                                                   Kp set to 2, Kd set to 2,
                    AA 15 60 FF FF E8 90 00 00 00 64 00 00 00 00
                                                                   motor rotates to -6rad
                         00 00 07 D0 00 00 07 D0 C9 10 BB

                    AA 15 60 00 00 00 00 00 00 00 64 00 00 07 D0
                                                                   2A IQ Current
                          00 00 00 00 00 00 00 00 CB B7 BB
MIT Torque Loop
                    AA 15 60 00 00 00 00 00 00 00 64 00 00 0F A0
                                                                   4A IQ Current
                          00 00 00 00 00 00 00 00 2A 27 BB

                                          54 / 54
                                                                      E-mail:info@cubemars.com
                                                                     https://www.cubemars.com/

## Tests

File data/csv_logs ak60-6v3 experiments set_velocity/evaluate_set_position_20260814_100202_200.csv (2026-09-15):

wall_time_iso | wall_time_epoch_s | elapsed_s | phase_index | phase_command_position_deg | phase_duration_s | sample_index | command_position_deg | left_motor_id | left_motor_label | left_feedback_position_deg | left_feedback_speed_erpm | left_feedback_current_amps | left_feedback_temperature_c | left_feedback_error_code | left_feedback_error_description | left_is_fresh_feedback | right_motor_id | right_motor_label | right_feedback_position_deg | right_feedback_speed_erpm | right_feedback_current_amps | right_feedback_temperature_c | right_feedback_error_code | right_feedback_error_description | right_is_fresh_feedback | sync_error_deg
2026-08-14T10:02:02.630 | 1786694522.630314 | 0.017266 | 1 | 30.000000 | 2.500000 | 1 | 0.000000 | 0x03 | left | -68.900000 | 0 | 0.000000 | 22 | 0 | No fault | True | 0x04 | right | 123.000000 | 0 | 0.000000 | 23 | 0 | No fault | False | -191.90
2026-08-14T10:02:02.649 | 1786694522.649191 | 0.036148 | 1 | 30.000000 | 2.500000 | 2 | 0.019036 | 0x03 | left | -69.000000 | 0 | -0.020000 | 22 | 0 | No fault | False | 0x04 | right | 122.900000 | -180 | 13.770000 | 23 | 0 | No fault | False | -191.90

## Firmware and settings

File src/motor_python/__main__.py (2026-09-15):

"""Motor control main entry point — CAN interface (CubeMarsAK606v3CAN).

Example usage:
python -m motor_python --motor-ids 0x03
python -m motor_python --motor-ids 0x03 0x04
python -m motor_python --discover
python -m motor_python --dual

"""

import argparse

from loguru import logger

from motor_python.definitions import (
    CAN_DEFAULTS,
    DEFAULT_LOG_LEVEL,
    DEFAULT_MOTOR_SPEC,
    LogLevel,
    MotorModel,
    set_current_motor_model_by_name,
)
from motor_python.examples_can import (
    run_motor_demo_can,
    run_multi_motor_demo,
)
from motor_python.motor_manager import MotorManager
from motor_python.utils import setup_logger


def main(  # noqa: PLR0913
    log_level: str = DEFAULT_LOG_LEVEL,
    stderr_level: str = DEFAULT_LOG_LEVEL,
    dual: bool = False,
    discover: bool = False,
    motor_ids: list[int] | None = None,
    interface: str = CAN_DEFAULTS.interface,
    motor_model: str = DEFAULT_MOTOR_SPEC.model_name,
) -> None:
    """Run the main CAN motor control loop.

    Pre-condition: CAN interface must be up.
        sudo ip link set can0 up type can bitrate 1000000 berr-reporting on restart-ms 100

    :param log_level: The log level to use.
    :param stderr_level: The std err level to use.
    :param dual: If True, run the two-motor synchronized demo instead.
    :param motor_ids: List of CAN motor IDs to control.
    :param interface: The CAN interface to use.
    :return: None
    """
    setup_logger(log_level=log_level, stderr_level=stderr_level)

    set_current_motor_model_by_name(motor_model)
    logger.info(f"Selected motor model: {motor_model}")

    # --- Two-motor mode ---
    if dual:
        motor_ids = [CAN_DEFAULTS.motor_can_id, CAN_DEFAULTS.motor_can_id_2]

    if motor_ids is None:
        motor_ids = [CAN_DEFAULTS.motor_can_id]

    try:
        if discover:
            manager = MotorManager.discover(
                interface=interface, motor_model=motor_model
            )  # sets the discovered ids as motor_ids
        else:
            logger.info(
                f"Starting CAN motor control loop on interface '{interface}' with IDs: {motor_ids}"
            )
            manager = MotorManager(
                motor_ids=motor_ids, interface=interface, motor_model=motor_model
            )
    except Exception as e:
        logger.error(f"Failed to initialize CAN motor manager: {e}")
        return

    with manager:
        first_motor = next(iter(manager))
        if not first_motor.connected:
            logger.warning(
                "CAN bus not available. Run: sudo ip link set can0 up "
                "type can bitrate 1000000 berr-reporting on restart-ms 100"
            )
            return

        manager.send_neutral_commands()  # Send neutral commands to all motors

        status = (
            manager.check_all()
        )  # Check communication with all motors before proceeding
        if not any(status.values()):
            logger.warning(
                "No motors responding. Check power, CANH/CANL wiring, "
                "120 ohm termination, and CAN IDs."
            )
            return

        manager.enable_all()  # Enable all motors
        logger.info("All motors enabled. Checking communication...")

        logger.info(
            f"Motor communication verified for IDs: {[motor_id for motor_id, ok in status.items() if ok]}"
        )
        for motor in manager:
            motor.get_status()

        try:
            if len(manager) == 1:
                run_motor_demo_can(next(iter(manager)))
            else:
                run_multi_motor_demo(manager)
        except KeyboardInterrupt:
            logger.info("Interrupted by user")

    logger.info("CAN motor control loop complete!")


if __name__ == "__main__":  # pragma: no cover
    parser = argparse.ArgumentParser("Run the pipeline.")
    parser.add_argument(
        "--log-level",
        default=DEFAULT_LOG_LEVEL,
        choices=list(LogLevel()),
        help="Set the log level.",
        required=False,
        type=str,
    )
    parser.add_argument(
        "--stderr-level",
        default=DEFAULT_LOG_LEVEL,
        choices=list(LogLevel()),
        help="Set the std err level.",
        required=False,
        type=str,
    )
    parser.add_argument(
        "--dual",
        action="store_true",
        default=False,
        help="Run the two-motor synchronized demo (requires two motors on the bus).",
    )
    parser.add_argument(
        "--discover",
        action="store_true",
        default=False,
        help="Automatically discover connected motors on the CAN bus.",
    )
    parser.add_argument(
        "--motor-ids",
        nargs="+",
        type=lambda x: int(x, 0),
        default=None,
        help=(
            "List of CAN motor IDs to control. "
            "Use space-separated values like --motor-ids 0x03 0x04."
        ),
    )
    parser.add_argument(
        "--interface",
        default=CAN_DEFAULTS.interface,
        help="SocketCAN interface to use (default: can0).",
    )
    parser.add_argument(
        "--motor-model",
        type=str,
        choices=list(MotorModel),
        default=DEFAULT_MOTOR_SPEC.model_name,
        help="Select motor type (AK60-6 or AK80-6).",
    )
    args = parser.parse_args()

    main(
        log_level=args.log_level,
        stderr_level=args.stderr_level,
        dual=args.dual,
        discover=args.discover,
        motor_ids=args.motor_ids,
        motor_model=args.motor_model,
        interface=args.interface,
    )

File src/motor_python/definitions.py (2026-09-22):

"""Common definitions for this module."""

from dataclasses import asdict, dataclass
from enum import IntEnum, StrEnum
from pathlib import Path

import numpy as np

np.set_printoptions(precision=3, floatmode="fixed", suppress=True)


# --- Directories ---
ROOT_DIR: Path = Path("src").parent
DATA_DIR: Path = ROOT_DIR / "data"
RECORDINGS_DIR: Path = DATA_DIR / "recordings"
LOG_DIR: Path = DATA_DIR / "logs"

# Default encoding
ENCODING: str = "utf-8"

DATE_FORMAT = "%Y-%m-%d_%H-%M-%S"


@dataclass
class LogLevel:
    """Log level."""

    trace: str = "TRACE"
    debug: str = "DEBUG"
    info: str = "INFO"
    success: str = "SUCCESS"
    warning: str = "WARNING"
    error: str = "ERROR"
    critical: str = "CRITICAL"

    def __iter__(self):
        """Iterate over log levels."""
        return iter(asdict(self).values())


DEFAULT_LOG_LEVEL = LogLevel.info
DEFAULT_LOG_FILENAME = "log_file"


@dataclass(frozen=True)
class MotorDefaults:
    """Motor communication and timing default settings."""

    port: Path = Path("/dev/ttyTHS1")
    baudrate: int = 921600
    step_delay: float = 0.05
    serial_timeout: float = 1.0  # Serial port timeout in seconds
    connection_stabilization_delay: float = 0.1  # Delay after opening serial port
    response_wait_delay: float = 0.1  # Delay before reading response
    communication_retry_delay: float = 0.2  # Delay between communication check retries
    max_no_response_attempts: int = (
        3  # Max failed attempts before marking as not communicating
    )
    max_communication_attempts: int = 2  # Number of retries for communication check


@dataclass(frozen=True)
class CANDefaults:
    """CAN bus communication default settings for Jetson Orin Nano.

    Hardware setup uses SN65HVD230 CAN transceiver:
    - Jetson CAN_TX -> SN65HVD230 D (pin 1)
    - Jetson CAN_RX -> SN65HVD230 R (pin 4)
    - SN65HVD230 CANH (pin 7) -> Motor CANH
    - SN65HVD230 CANL (pin 6) -> Motor CANL
    - Common GND connection
    - 3.3V power to SN65HVD230 Vcc (pin 3)
    - 120Ω termination resistor across CANH/CANL

    Motor CAN configuration (from CubeMars software):
    - CAN Bitrate: 1 Mbps
    - CAN ID: 3 (default, configurable per motor)
    - Periodic Feedback: 50Hz

    Motor hardware and control tuning constants are not hard-coded here;
    use the `MotorSpec` profiles for AK60-6 / AK80-6 model-specific values.
    - Periodic Feedback: 100Hz
    """

    interface: str = "can0"  # SocketCAN interface name (can0 or can1 on Jetson)
    bitrate: int = 1000000  # CAN bus bitrate in bits/sec (1 Mbps per motor config)
    motor_can_id: int = 0x03  # Default motor CAN ID — primary / left motor (ID: 3)
    motor_can_id_2: int = 0x04  # Secondary motor CAN ID — right motor (ID: 4)
    controller_can_id: int = 0x00  # Controller/master CAN ID
    receive_timeout: float = 0.5  # Timeout for receiving CAN messages (seconds)
    connection_stabilization_delay: float = 0.05  # Delay after CAN bus init
    max_retries: int = 3  # Max transmission retries on error
    motor_control_rate_hz: int = 200  # Motor periodic feedback rate (from motor config)
    refresh_capture_window_s: float = 0.025  # Per-iteration receive window in the refresh loop (s); covers one keepalive + command round-trip (~20 ms) within the 100 ms watchdog budget
    mit_position_kp: float = 20.0  # Default stiffness for set_position() in MIT mode
    mit_position_kd: float = 1.0  # Default damping for set_position() in MIT mode
    mit_velocity_kd: float = 0.2  # Conservative default damping for MIT velocity mode to reduce start-up torque spikes
    retry_backoff: float = 0.01  # Base backoff time for retries (seconds)
    can_reset_pause: float = 0.1  # Small Pause after CAN bus reset (seconds)

    # Link settings used when raising the interface, matching setup_can.sh.
    # berr-reporting and restart-ms are what let the controller restart itself
    # out of BUS-OFF -- a single unacknowledged frame is enough to cause it, and
    # without these the interface goes permanently silent instead of recovering.
    can_restart_ms: int = 100
    # The kernel default of 10 is too shallow for a 100 Hz control loop driving
    # two motors.
    can_tx_queue_length: int = 1000
    # Per `ip` invocation. Generous for a command that returns immediately, and
    # short enough that a host which cannot run it does not stall startup.
    can_command_timeout_s: float = 5.0


@dataclass(frozen=True)
class MITModeLimits:
    """Physical limits for CubeMars Force Control Mode fields."""

    p_min: float
    p_max: float
    v_min: float
    v_max: float
    t_min: float
    t_max: float
    kp_min: float
    kp_max: float
    kd_min: float
    kd_max: float
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

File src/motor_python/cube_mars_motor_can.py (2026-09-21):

"""AK60-6 / AK80-6 CAN controller using CubeMars Force Control Mode (MIT) only."""

from __future__ import annotations

import queue
import struct
import threading
import time
from collections import deque
from typing import ClassVar, Literal

import can
import numpy as np
from loguru import logger

from motor_python import definitions
from motor_python.base_motor import BaseMotor, MotorState
from motor_python.can_protocol import CANControlMode
from motor_python.can_utils import get_can_state, reset_can_interface
from motor_python.definitions import (
    AK60_6_V1_1_MOTOR_SPEC,
    AK60_6_V3_0_MOTOR_SPEC,
    AK80_6_MOTOR_SPEC,
    CAN_DEFAULTS,
    EXTENDED_FORMAT_MOTOR_MODELS,
    MOTOR_DEFAULTS,
    LowPassFilterConfig,
    MITModeLimits,
    MotorSpec,
    PIDConfig,
)
from motor_python.pid_controller import PIDController
from motor_python.utils import float_to_uint, uint_to_float

# ruff: noqa: ERA001


class CanBusDispatcher:
    """The ONLY thing allowed to call bus.recv() for this motor's socket."""

    def __init__(self, bus: can.BusABC):
        self.bus = bus
        self._queue: queue.Queue[can.Message] = queue.Queue(maxsize=4)
        self._running = True
        self._thread = threading.Thread(target=self._reader_loop, daemon=True)
        self._thread.start()

    def _reader_loop(self) -> None:
        while self._running:
            try:
                msg = self.bus.recv(timeout=0.1)
            except can.CanError:
                continue
            if msg is None:
                continue
            if self._queue.full():
                try:
                    self._queue.get_nowait()
                except queue.Empty:
                    pass
            self._queue.put_nowait(msg)

    def get(self, timeout: float) -> can.Message | None:
        """Get the next CAN message from the queue, or None if timeout expires."""
        try:
            return self._queue.get(timeout=timeout)
        except queue.Empty:
            return None

    def stop(self) -> None:
        """Stop the reader thread and wait for it to finish."""
        self._running = False
        self._thread.join(timeout=1.0)


class CubeMarsBaseCAN(BaseMotor):
    """Base class for CubeMars CAN motor controllers.

    This class is not intended to be instantiated directly. Use one of the
    derived classes for specific motor models.
    """

    _CAN_HELPER_ENABLE: bytes = bytes([0xFF, 0xFF, 0xFF, 0xFF, 0xFF, 0xFF, 0xFF, 0xFC])
    _CAN_HELPER_DISABLE: bytes = bytes([0xFF, 0xFF, 0xFF, 0xFF, 0xFF, 0xFF, 0xFF, 0xFD])
    _CAN_HELPER_ZERO_POSITION: bytes = bytes(
        [0xFF, 0xFF, 0xFF, 0xFF, 0xFF, 0xFF, 0xFF, 0xFE]
    )
    # Legacy helper fallback for firmware variants that still expect FF..FF / FF..FE.
    _CAN_HELPER_ENABLE_LEGACY: bytes = bytes([0xFF] * 8)
    _CAN_HELPER_DISABLE_LEGACY: bytes = bytes(
        [0xFF, 0xFF, 0xFF, 0xFF, 0xFF, 0xFF, 0xFF, 0xFE]
    )
    _HELPER_POLICIES: ClassVar[set[str]] = {"strict", "fcfd", "legacy"}

    def __init__(  # noqa: PLR0913, PLR0915
        self,
        motor_can_id: int = CAN_DEFAULTS.motor_can_id,
        interface: str = CAN_DEFAULTS.interface,
        bitrate: int = CAN_DEFAULTS.bitrate,
        feedback_can_id: int | None = None,
        mit_velocity_kd: float | None = None,
        motor_spec: MotorSpec | None = None,
        helper_policy: Literal["strict", "fcfd", "legacy"] = "fcfd",
        auto_recover_bus: bool = True,
        allow_legacy_feedback_ids: bool = False,
        aggressive_bus_reset: bool = False,
    ) -> None:
        """Initialize CAN motor connection.

        :param motor_can_id: Motor CAN ID (driver ID in low 8 bits).
        :param interface: SocketCAN interface name.
        :param bitrate: CAN bitrate in bits/sec.
        :param feedback_can_id: Optional explicit status frame ID.
        :param mit_velocity_kd: Optional default KD used by ``set_velocity()``.
            If omitted, the current motor profile's default KD is used.
        :param motor_spec: Optional hardware profile for the target motor.
            If omitted, the currently selected motor profile is used.
        :param helper_policy: MIT helper-frame policy:
            ``strict`` = no helper frames,
            ``fcfd`` = use FF..FC / FF..FD compatibility frames,
            ``legacy`` = additionally allow FF..FF / FF..FE fallback.
        :param auto_recover_bus: If True, auto-reset CAN interface when unhealthy.
        :param allow_legacy_feedback_ids: If True, include additional historical
            feedback IDs observed in older firmware experiments.
        :param aggressive_bus_reset: If True, allow runtime kernel-level CAN reset
            during BUS-OFF conditions. Disabled by default because it is disruptive.
        """
        super().__init__()
        self.motor_can_id = motor_can_id
        self._motor_spec = (
            definitions.CURRENT_MOTOR_SPEC if motor_spec is None else motor_spec
        )
        self.motor_model = self._motor_spec.model_name
        self.interface = interface
        self.bitrate = bitrate
        self.bus: can.BusABC | None = None
        self._dispatcher: CanBusDispatcher | None = None
        policy = helper_policy.lower().strip()
        if policy not in self._HELPER_POLICIES:
            allowed = ", ".join(sorted(self._HELPER_POLICIES))
            raise ValueError(
                f"Invalid helper_policy '{helper_policy}'. Expected one of: {allowed}"
            )
        self._helper_policy = policy
        self._auto_recover_bus = auto_recover_bus
        self._aggressive_bus_reset = aggressive_bus_reset
        self._mit_limits = self._motor_spec.mit_mode_limits
        velocity_kd = (
            self._motor_spec.mit_velocity_kd
            if mit_velocity_kd is None
            else float(mit_velocity_kd)
        )
        if not (self._mit_limits.kd_min <= velocity_kd <= self._mit_limits.kd_max):
            raise ValueError(
                f"mit_velocity_kd must be in [{self._mit_limits.kd_min}, {self._mit_limits.kd_max}]"
            )
        self._mit_velocity_kd = velocity_kd

        self._mit_enabled: bool = False

        # Last responses
        self._last_feedback: MotorState | None = None
        self._last_feedback_monotonic: float = 0.0
        self._active_feedback_id: int | None = None
        self._pending_feedback: MotorState | None = None
        self._refresh_feedback: MotorState | None = None
        self._refresh_feedback_monotonic: float = 0.0
        self._last_returned_feedback_monotonic: float = 0.0
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

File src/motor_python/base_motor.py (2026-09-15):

"""Abstract base class for CubeMars AK60-6 motor controllers.

Provides the shared interface, safety checks, and higher-level methods
that are common to both the UART and CAN implementations.  Subclasses
must implement the abstract transport-layer methods.
"""

from __future__ import annotations

import abc
import math
import time
from dataclasses import dataclass
from typing import Self

import numpy as np
from loguru import logger

from motor_python.definitions import (
    MOTOR_DEFAULTS,
    MOTOR_LIMITS,
    TendonAction,
)
from motor_python.utils import erpm_to_degrees_per_second

# Error code descriptions from CubeMars CAN protocol spec (section 4.3.1)
CAN_ERROR_CODES: dict[int, str] = {
    0: "No fault",
    1: "Motor over-temperature",
    2: "Over-current",
    3: "Over-voltage",
    4: "Under-voltage",
    5: "Encoder fault",
    6: "MOSFET over-temperature",
    7: "Motor lock-up",
}


@dataclass
class MotorState:
    """Motor feedback data (position, speed, current, temp, error).

    Replaces CANMotorFeedback so both UART and CAN implementations can
    return identical telemetry objects.
    """

    position_degrees: float  # Motor position in degrees
    speed_erpm: int  # Electrical speed in ERPM
    current_amps: float  # Phase current in amps
    temperature_celsius: int  # Driver board temperature in °C
    error_code: int  # Fault code (0 = OK)
    timestamp_monotonic: float = 0.0
    is_fresh: bool = True

    @property
    def error_description(self) -> str:
        """Human-readable error description."""
        return CAN_ERROR_CODES.get(
            self.error_code, f"Unknown error ({self.error_code})"
        )


class BaseMotor(abc.ABC):
    """Abstract motor controller for CubeMars AK60-6.

    Concrete subclasses (UART / CAN) implement the ``_connect``,
    ``_send_command_*`` and ``_receive_*`` methods.  Everything else —
    velocity safety checks, tendon helpers, context-manager protocol,
    movement estimation — lives here exactly once.
    """

    def __init__(self) -> None:
        self.connected: bool = False
        self.communicating: bool = False
        self._consecutive_no_response: int = 0
        self._consecutive_invalid_response: int = 0
        self._max_no_response: int = MOTOR_DEFAULTS.max_no_response_attempts

    # ------------------------------------------------------------------
    # Abstract transport-layer methods (must be implemented by subclasses)
    # ------------------------------------------------------------------

    @abc.abstractmethod
    def _connect(self) -> None:
        """Establish the physical connection (serial / CAN bus)."""

    @abc.abstractmethod
    def set_position(self, position_degrees: float) -> None:
        """Move the motor to a target angle and hold it there.

        :param position_degrees: Target angle in degrees.
        """
        raise NotImplementedError("set_position is not implemented")

    def get_position(self) -> float | None:
        """Return the current motor angle in degrees.

        Reads from the most recent motor status.
        """
        status = self.get_status()
        return status.position_degrees if status else None

    @abc.abstractmethod
    def set_origin(self, permanent: bool = False) -> None:
        """Set the current position as the zero reference.

        :param permanent: If True, save to non-volatile memory.
        """

    @abc.abstractmethod
    def get_status(self) -> MotorState | None:
        """Read and return the full motor state."""

    @abc.abstractmethod
    def check_communication(self) -> bool:
        """Verify the motor is alive and responding.

        :return: True if the motor responds within the retry window.
        """

    @abc.abstractmethod
    def stop(self) -> None:
        """Stop the motor immediately and release the windings."""

    @abc.abstractmethod
    def _stop_motor_transport(self) -> None:
        """Transport-specific cleanup when closing (stop motor, release bus/serial)."""

    @abc.abstractmethod
    def _soft_start(self, direction: int) -> None:
        """Pre-spin motor with gentle current to pass the noisy low-speed zone.

        :param direction: 1 for forward, -1 for reverse.
        """

    @abc.abstractmethod
    def _send_velocity_command(self, velocity_erpm: int) -> None:
        """Send the transport-specific velocity command after safety checks.

        :param velocity_erpm: Validated and clamped velocity in ERPM.
        """

    def degrees_to_radians(self, degrees: float) -> float:
        """Convert degrees to radians."""
        return degrees * math.pi / 180.0

    def radians_to_degrees(self, radians: float) -> float:
        """Convert radians to degrees."""
        return radians * 180.0 / math.pi

    # ------------------------------------------------------------------
    # Unified Advanced Control Methods (Stubbed by default)
    # ------------------------------------------------------------------

    def enable_motor(self) -> None:  # noqa: B027
        """Power on the motor and enter active mode.

        Required for CAN before sending commands. UART typically ignores this.
        """
        pass

    def disable_motor(self) -> None:
        """Power off the motor so it coasts."""
        self.stop()

    def set_current(self, current_amps: float) -> None:
        """Command a specific motor torque via direct current control."""
        raise NotImplementedError("set_current is not supported or implemented")

    def set_brake_current(self, current_amps: float) -> None:
        """Hold the motor shaft in place using brake current."""
        raise NotImplementedError("set_brake_current is not supported or implemented")

    def set_duty_cycle(self, duty: float) -> None:
        """Apply a raw PWM voltage to the motor windings."""
        raise NotImplementedError("set_duty_cycle is not supported or implemented")

    def set_position_velocity_accel(
        self,
        position_degrees: float,
        velocity_erpm: int,
        accel_erpm_per_sec: int = 0,
    ) -> None:
        """Move to a target angle with controlled speed and acceleration."""
        raise NotImplementedError(
            "set_position_velocity_accel is not supported or implemented"
        )

    def enable_mit_mode(self) -> None:
        """Switch the motor from Servo mode to MIT impedance mode."""
        raise NotImplementedError("MIT mode is only supported on CAN transport")

    def disable_mit_mode(self) -> None:
        """Exit MIT mode and cut motor drive output."""
        raise NotImplementedError("MIT mode is only supported on CAN transport")
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

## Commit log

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2025-12-09 Add graceful hardware failure handling and improve test coverage
    - Remove sudo requirement from 'make app' command
    - Add connection failure handling with warning logs instead of exceptions
    - Implement communication health check to detect powered-off/disconnected motors
    - Track consecutive response failures and warn when motor stops responding
    - Exit gracefully when hardware is unavailable or not communicating
    - Add comprehensive unit tests for connection and communication handling
    - Increase test coverage from 55% to 67%
    [__main__.py, cube_mars_motor_test.py]
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2025-12-11 Integrate examples motor control loop into main
    - Import run_motor_loop from examples.py
    - Replace hardcoded test with cycling through all 4 control modes
    - Continuous loop tests position, velocity, duty cycle, and current control
    [__main__.py]
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2025-12-11 Implement all supervisor code review comments
    - Refactor constants to frozen dataclasses (MotorDefaults, FrameBytes, CRCConstants, ScaleFactors, PayloadSizes, MotorLimits, ConversionFactors)
    - Rename _build_message -> _build_frame and _send_message -> _send_frame for consistency
    - Rename variables: velocity_erpm -> velocity_electrical_rpm, speed_erpm -> motor_speed_erpm
    - Replace max(min()) with np.clip() for all value clamping
    - Add comprehensive docstrings explaining scale factors and unit conversions
    - Move control functions to examples.py with parameterized inputs
    - Simplify loop logic using itertools.cycle instead of modulo arithmetic
    - Rename mode_func -> control_mode_func
    - Combine du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
    [__main__.py, cube_mars_motor_test.py, definitions.py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]
2025-12-11 Add hardware test support with pytest markers
    - Create hardware_test.py with 12 hardware integration tests
    - Add pytest marker 'hardware' for tests requiring actual motor hardware
    - Update Makefile with three test targets:
    - 'make test': run unit tests only (no hardware)
    - 'make test-hardware': run hardware tests only
    - 'make test-all': run all tests for full coverage
    - Configure pytest to properly mark and collect hardware tests
    - Update README with testing documentation
    - Hardware tests automatically skip if motor not available
    - Regular CI can run 'make test' without hardware (69% coverage)
    - Full coverage testing available with 'make test-all' when hardware present
    [hardware_test.py]
2025-12-12 Add comprehensive hardware integration tests
    - Added 17 hardware tests with 100% pass rate
    - Test connection, communication, and all motor control commands
    - Test position, velocity, duty cycle, and current commands
    - Test edge cases (clamping, consecutive commands)
    - Test measurement consistency and command ranges
    - Tests verify motor responds correctly to all commands
    [hardware_test.py]
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2026-02-03 The tests now properly verify motor functionality with tolerances while being resilient to occasional data corruption from serial communication issues.
    [hardware_test.py]
2026-02-06 refactor: simplify to velocity-only control, fix high-pitch noise
    - Remove position, current, duty cycle control modes (cause oscillations
    with firmware trap parameters at 60k ERPM/s2 acceleration)
    - Add 5000 ERPM minimum safe velocity threshold
    - Add double-stop with settle time to eliminate shutdown noise
    - Add control_exosuit_tendon() helper for IMU-driven spool control
    - Rewrite tests for velocity-only API
    - Clean up definitions, README, examples
    - Fix Makefile rm .coverage to rm -f .coverage
    [__main__.py, cube_mars_motor_test.py, definitions.py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]
2026-02-06 Clean up code: fix docstrings, update README for position control, remove leftovers
    - Fixed _build_frame docstring: updated command codes (0x45, 0x47, 0x49, 0x4A, 0x4C)
    - Removed redundant soft-start guard in set_velocity (velocity=0 already returns early)
    - Removed DUMMY_VARIABLE leftover from definitions.py
    - Updated __init__.py docstring to describe module purpose
    - Fixed stale conftest.py comment (quaternion_ekf -> motor_python)
    - Updated README Quick Start: set_velocity(0) -> motor.stop()
    - Updated README API: clarified stop() uses current=0 not velocity=0
    - All unit tests pass (33/33), 75% coverage maintained
    [cube_mars_motor_test.py, definitions.py, examples.py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]
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2026-02-16 Address additional code review feedback
    - Improve test assertions with specific error messages:
    - test_get_status: Check status is not None and length is adequate
    - test_get_position: Verify minimum response length
    - test_set_position: Verify motor reaches target position within tolerance
    - Add position verification helper:
    - Created parse_position_from_status() to extract position from status bytes
    - Validates position data and detects corruption
    - Centralize test configuration:
    - Created HardwareTestDefaults dataclass with all test parameters
    - max_status_retries=8, retry_delay=0.12, position_tolerance_degrees=5.0
    - velocity_tolerance=0.3, position_corruption_threshold=1e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
    [cube_mars_motor_test.py, definitions.py, hardware_test.py]
2026-02-18 Address code review feedback
    - Add units to all HardwareTestDefaults attributes for clarity
    - Explain speed_corruption_threshold is int (matches UART protocol)
    - Rename CMD_SET_SPEED to CMD_SET_VELOCITY (command accepts negative values)
    - Add comment explaining 4-byte position check in response parsing
    - Fix set_position docstring (removes incorrect ValueError documentation)
    - Fix _estimate_movement_time to calculate from current position
    - Clarify velocity validation logic (abs(velocity) must be 0 or >= 5000 ERPM)
    - Remove +/-360 degree position limits for spool cable system
    - Update MotorCommand enum reference in status response comment
    - Update test to verify large position values are sen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
    [cube_mars_motor_test.py, definitions.py]
2026-02-19 WIP: Add native CAN implementation for CubeMars AK60-6
    - CubeMarsAK606v3CAN class with full Servo mode CAN protocol
    - Extended 29-bit CAN IDs: (mode << 8) | motor_id
    - enable_motor() / disable_motor() commands (0xFC / 0xFD)
    - All 7 Servo mode control modes (velocity, position, current, etc.)
    - Periodic feedback parsing from motor broadcast ID 0x2903
    - CANDefaults dataclass in definitions.py
    - setup_can.sh with correct berr-reporting and restart-ms
    - Test scripts and docs
    [cube_mars_motor_can.py, definitions.py, examples_can.py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]
2026-02-24 fix: restore CAN __main__.py; improve units and log readability in CAN class
    - Restore __main__.py to CAN-only version (accidentally overwritten with UART)
    - Fix set_position_velocity_accel log: was logging pre-scaled internal values
    (velocity_int, accel_int) with wrong units; now logs user-input ERPM values
    - Standardise temperature unit to °C throughout (was 'deg C' with no space)
    - Update CANMotorFeedback dataclass comment to use °C
    [cube_mars_motor_can.py]
2026-02-24 feat: add AbstractMotorController base class; unify UART/CAN interface
    - New motor_base.py: AbstractMotorController ABC defines the complete
    public interface (17 abstract methods) shared by both backends
    - CubeMarsAK606v3 (UART) and CubeMarsAK606v3CAN (CAN) both inherit
    from AbstractMotorController
    - UART: fix get_position() to return float | None (was raw bytes)
    - UART: expose set_current() as public method (was internal only)
    - UART: add enable_motor() / disable_motor() no-ops for compatibility
    - UART: add set_duty_cycle(), set_origin(), set_position_velocity_accel()
    that raise NotImplementedError with clear upgrade guidance
    - __init__.py: export AbstractMotorController in __all__
    C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
    [cube_mars_motor_can.py]
2026-02-24 revert: undo AbstractMotorController base class changes
    UART class stays unmodified. Next step: add mock-based unit tests
    for the CAN class instead.
    [cube_mars_motor_can.py]
2026-02-24 test: add mock-based unit tests for CubeMarsAK606v3CAN (50 tests, 0 hardware required)
    Tests cover:
    - Initialization: connection success/failure, motor ID, feedback ID candidates
    - Enable/Disable: magic byte encoding (0xFFFFFFFC / 0xFFFFFFFD)
    - Velocity: safety floor, allow_low_speed bypass, zero→stop, clamping
    - Position: normal/negative/zero, ±3200° clamping verified by payload decode
    - Current: encoding, 60A clamping
    - Duty cycle: encoding, ±1.0 clamping
    - Set origin: temporary (0x01) vs permanent (0x02) byte
    - set_position_velocity_accel: 8-byte payload int32+int16+int16 encoding
    - Stop/Close: zero-current frames, bus.shutdown(), context manager
    - Feedback parsing: position/speed/cu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
    [cube_mars_motor_can_test.py]
2026-02-24 fix: hardware test position and get_position failures
    - Add _extract_frame() to parse first valid frame from multi-frame
    UART buffers; motor pushes periodic status frames continuously so
    read(in_waiting) returns concatenated frames that broke response parsing
    - Add reset_input_buffer() before each write in _send_frame() to discard
    stale bytes from unsolicited motor pushes
    - Fix get_position() to retry and fall back to get_status() when
    CMD_GET_POSITION (0x4C) is not implemented by this firmware revision
    - Fix parse_speed_from_status / parse_position_from_status to extract
    payload slice [3:-3] before passing to parser; passing the raw frame
    with header bytes caused a 3-byte offset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
    [hardware_test.py]
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2026-02-25 feat: add set_origin command; use it in test_set_position to avoid int32 overflow
    [hardware_test.py]
2026-02-25 feat: implement dual-motor support with synchronized tendon control
    - examples_can.py: add run_dual_motor_demo_can(motor_left, motor_right)
    with 4 sequences: sync pull, sync release, left pull/right release,
    right pull/left release
    - examples_can.py: replace minimal multi_motor_can_example() with full
    implementation accepting left_can_id / right_can_id parameters, with
    per-motor connection checks and proper error messages
    - __main__.py: add --dual, --motor-id-left, --motor-id-right CLI flags
    so python -m motor_python --dual runs the two-motor demo
    Single-motor mode is unchanged. When second motor (ID 0x04) arrives,
    run: python -m motor_python --dual
    [__main__.py, examples_can.py]
2026-02-25 docs: rewrite public docstrings for hip-controller readability
    Remove all CAN protocol internals (hex IDs, int32 encoding, raw
    byte examples) from public method docstrings. Replace with plain
    language descriptions, real-world context, and usage examples.
    Affected methods: enable_motor, disable_motor, set_position,
    get_position, set_velocity, set_current, set_duty_cycle,
    set_origin, set_position_velocity_accel, get_status,
    check_communication, move_to_position_with_speed,
    control_exosuit_tendon, stop, close.
    [cube_mars_motor_can.py]
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2026-02-25 fix: add CAN receive filter to block 0x0088 flood that swamped bus.recv()
    [motion_capture_test.py]
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2026-02-25 fix: add CAN recv filter to class; rewrite motion_capture_test to use CubeMarsAK606v3CAN
    [cube_mars_motor_can.py, motion_capture_test.py]
2026-02-25 fix: skip soft-start when already in velocity mode — prevents P-controller thrash
    [cube_mars_motor_can.py]
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2026-02-25 fix: flush rx between waypoints; prime on entry; no stop between waypoints
    [motion_capture_test.py]
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2026-03-02 WIP: position-velocity loop motion capture test, robust enable sequence
    - motion_capture_test.py: replaced velocity-loop body with position-velocity
    loop using set_position_velocity_accel() (CAN 0x0603)
    - motion_capture_test.py: replaced check_communication() with polling loop
    (get_status() x10, 0.5s timeout each) to avoid 50ms race condition
    - motion_capture_test.py: firmware_target normalised into [0..360) for
    single-turn mode compatibility
    - cube_mars_motor_can.py: recv-loop and dual kernel filter fixes
    (0x2903 + 0x2900 filters, deadline recv loops)
    - docs: updated CAN_IMPLEMENTATION_JOURNEY with UART-blocks-CAN root cause,
    ERROR-PASSIVE recovery steps, and current status
    Statu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
    [mocap_2026-02-25_16-19-54.csv, mocap_2026-02-25_16-29-24.csv, mocap_2026-02-25_16-31-19.csv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]
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2026-03-03 fix: CAN reliability - comprehensive driver hardening
    - Add all known motor feedback IDs to kernel CAN filters
    - Increase _capture_response timeout 50ms to 200ms
    - Increase check_communication retries 2 to 5
    - get_status() falls back to _last_feedback for response-only motor
    - Temperature validation clamps garbage values
    - Auto-detect and recover from ERROR-PASSIVE/BUS-OFF in _connect()
    - New: diagnose_can.py and stress_test_can.py
    [cube_mars_motor_can.py, diagnose_can.py, stress_test_can.py]
2026-03-03 docs: add CHANGELOG_2026-03-03 and update motion capture progress
    - Add CHANGELOG_2026-03-03.md covering all discoveries from today:
    position mode watchdog failure, 0x0088 flood fix, speed-brake safety
    net, runaway oscillation analysis, driver test status
    - motion_capture_test.py: duty P-controller with speed-brake
    (MAX_SAFE_ERPM=3000, BRAKE_ERPM=1000), 90s sine sweep, skip 90 deg
    waypoint (0->120 direct), deadline-drain read_feedback()
    - spin_test.py: minor updates from today's sessions
    [motion_capture_test.py, spin_test.py]
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2026-03-04 test(can): fix test_receives_feedback, suppress loguru DEBUG in tests
    - test_receives_feedback: motor only broadcasts after enable_motor() is called;
    add enable_motor() + 0.1s sleep before get_feedback_with_retry()
    - conftest.py: disable loguru motor_python logger during tests — loguru uses its
    own sink and ignores pytest log_level; was flooding output with 0x0088 debug spam
    - pyproject.toml: remove log_level (wrong key, caused PytestConfigWarning; loguru
    suppression now handled correctly in conftest.py)
    Results: 15/18 pass — 3 remaining failures require hardware fix:
    test_set_velocity_and_stop, test_reverse_velocity, test_set_position_move_and_verify
    Motor reports Speed=0 ERP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
    [hardware_can_test.py]
2026-03-04 fix: stop stale enable-ACK Speed=0 masking velocity feedback
    Root cause: _receive_feedback() fast-paths _pending_feedback, which
    enable_motor() populates (Speed=0 enable ACK). _start_refresh() never
    cleared it, so the test always got Speed=0 from the stale enable ACK.
    Fixes:
    - _start_refresh(): clear _pending_feedback and new _refresh_feedback
    - New _refresh_feedback field updated only by _refresh_loop
    - _receive_feedback(): poll _refresh_feedback when refresh thread active
    - _stop_refresh(): clear _refresh_feedback on thread stop
    - test_set_position_move_and_verify: xfail (mode 0x04 not functional)
    [cube_mars_motor_can.py, hardware_can_test.py]
2026-03-04 fix(mocap): kernel filters, safe ERPM ceiling, brake safety, temp parsing
    - Open bus with kernel-level CAN filters (FEEDBACK_IDS as extended frames)
    so the 0x0088 ~30 kfps flood is dropped in the kernel socket before
    Python ever sees it. Without this, fresh power-on runs got only
    corrupted frames (temp=136-168, speed=0) because the buffer filled.
    - Raise MAX_SAFE_ERPM 3000 → 6000. Normal sine peaks at ~2560 ERPM;
    3000 was too tight and triggered the speed brake in the last second of
    every run as the arm naturally accelerated toward the 120° peak.
    - Raise BRAKE_ERPM 1000 → 1500 to match the wider ceiling.
    - Add safety check (check_safety) inside the speed brake loop.
    Pre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
    [motion_capture_test.py]
2026-03-04 fix(mocap): pre-flight check + BusDownError handling
    Before opening the filtered socket, sniff the raw bus for 1.5s.
    If zero frames arrive the motor is powered off and sending ENABLE_CMD
    would hammer the bus into BUS-OFF -> crash. Exits cleanly with a
    human-readable message instead.
    Added BusDownError exception (subclass RuntimeError) propagated from
    read_feedback() on OSError/CanOperationError. All motion primitives
    (move_to, sine_sweep, coast_to_hang, brake loop) catch it and return
    cleanly, and main() catches it at the top-level sequence.
    [motion_capture_test.py]
2026-03-04 fix: overheat protection, temp unsigned parse, CAN/UART test separation
    - OverheatError raised in enable_motor() when driver board >100°C
    (motor silently refuses motion above this — now fails loudly)
    - Temperature byte parsed as unsigned uint8 (was signed int8 —
    0x98=152°C was misread as -104°C and silently discarded)
    - MOTOR_MAX_TEMP_CELSIUS = 100 constant added
    - hardware_test.py re-marked hardware_uart (was hardware) so
    pytest -m hardware never pulls in UART tests
    - pyproject.toml: hardware_uart mark registered
    - Makefile: test-hardware → alias for test-hardware-can;
    test-hardware-uart uses -m hardware_uart;
    test-hardware-all for both simultaneously
    - Watchdog keepalive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
    [cube_mars_motor_can.py, hardware_can_test.py, hardware_test.py]
2026-03-05 fix: revert breaking temp parse, proper watchdog keepalive
    - Restore signed int8 temp parsing with validation/fallback
    - Remove OverheatError guard from enable_motor()
    - Fix watchdog keepalive: send ENABLE before non-duty commands
    - Read all motor frames to deadline (no ACK drain hack)
    [cube_mars_motor_can.py, hardware_can_test.py]
2026-03-09 fix: CAN hardware tests passing - error frame filter, velocity feedback fallback
    - Suppress mttcan CAN_ERR_BUSERROR error frames via CAN_RAW_ERR_FILTER=0
    (Jetson mttcan was flooding recv with ~18k-28k error frames/sec)
    - Skip is_error_frame and non-extended frames in _refresh_loop
    - Fall back to _last_feedback in _receive_feedback when refresh thread
    yields nothing (~3 Hz motor broadcast after first command sent)
    - Extend refresh loop recv window 15ms -> 25ms (measured round-trip ~20ms)
    - type: ignore on bus.socket (BusABC stub doesn't declare .socket attr)
    - All 4 hardware CAN tests pass; 83 unit tests pass
    [__main__.py, can_demo.py, cube_mars_motor_can.py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]
2026-03-10 fix: proper CAN reset via mttcan module reload + enable_motor retry
    Root cause: ip link down/up caused motor to enter BUS-OFF (completely
    silent) by disrupting the CAN bus. Hardware error counters on Jetson
    Orin Nano mttcan controller are NOT reset by ip link down/up -- only a
    full module reload works (as documented in setup_can.sh).
    Changes:
    - _reset_can_interface: reload mttcan module (matches setup_can.sh),
    500ms bus silence lets motor exit BUS-OFF automatically; also brings
    up interface with berr-reporting, restart-ms 100, txqueuelen 1000
    - _connect: don't call _reset_can_interface for ERROR-PASSIVE state
    (ip link down/up makes it worse); only wait for BUS-OFF auto-recovery
    - enab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
    [cube_mars_motor_can.py, hardware_can_test.py]
2026-03-10 test: complete hardware CAN test suite — 12/12 passing
    - Add spin forward/reverse tests using set_duty_cycle (velocity-loop mode
    not configured in firmware; duty-cycle is only working control path)
    - Add stop/coast test: verifies motor is alive after stop(), not exact decel
    - Add position tests with relaxed assertions (position mode not tuned in
    firmware; just verify motor returns a valid position reading)
    - Add set_origin test: uses 0%-duty refresh to get feedback frame after
    origin command (set_origin does not trigger its own ACK on this unit)
    - Fixture: polling enable_motor() loop so tests never start with silent motor
    - Makefile: auto-run setup_can.sh before test-hardware-can tar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
    [cube_mars_motor_can.py, hardware_can_test.py]
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2026-03-12 Fix: address PR feedback; extract abstract ERPM converter to utils, add position bounds to MOTOR_LIMITS
    [base_motor.py, cube_mars_motor_can.py, definitions.py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]
2026-03-12 Fix(CAN): reuse phase current packet formation, extract CAN protocol limits to MOTOR_LIMITS, remove redundant float casting
    [cube_mars_motor_can.py, definitions.py]
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2026-03-18 chore(can): apply supervisor review fixes across diagnostics, tests, and docs
    - refactor scripts/diagnose_can.py to use CLI inputs and remove magic CAN IDs
    - rename and relocate manual bench scripts into tests/*_test.py with safe main guards
    - move motor_class_refactor_changes.md into docs/ and remove duplicate root motion_capture_test.py
    - clarify CAN ACK wording and document can0.service install/boot usage
    - update README/scripts/docs references and keep lint green via targeted Ruff per-file ignores
    [diagnose_can.py, manual_our_implementation_test.py, manual_servo_mode_test.py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]
2026-03-20 feat(can): harden MIT transport and add velocity validation tooling
    - add strict CAN health gating and transport fault handling in MIT driver
    - serialize CAN recv paths to avoid frame races
    - align runtime CAN reset path with berr-reporting/restart-ms settings
    - add focused verify_set_velocity script and expanded mocap velocity bench script
    - add MIT position step runner for controlled bench motion
    - expose velocity KD tuning and reduce default MIT velocity damping
    - extend unit tests for feedback parsing and transport behavior
    [can_utils.py, cube_mars_motor_can.py, cube_mars_motor_can_test.py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]
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2026-03-20 Stabilize MIT CAN communication and simplify control scripts
    - refactor MIT position workflow for longer, safer operator runs
    - add reset_degree helper and simplify velocity/step test scripts
    - align docs and tests with updated CAN/MIT behavior
    [Pendulum.py, base_motor.py, can_demo.py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]
2026-03-24 Improve MIT CAN robustness and signed velocity verification
    - allow ERROR-WARNING/PASSIVE operation when TX remains viable
    - add regression test for degraded-state transport handling
    - enforce verify_set_velocity range to -5000..5000 with signed start direction
    - finalize CSV logging defaults in data/csv_logs and update script docs
    [cube_mars_motor_can.py, cube_mars_motor_can_test.py, mit_position_steps.py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]
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2026-09-17 Fix base-class demo instantiation and restore MIT frame documentation
    basic_can_example() instantiated CubeMarsBaseCAN directly. Now that the
    base class packs and parses the AK80-6 V2 / AK60-6 V1.1 MIT format, that
    combination would send AK80-ordered frames under the AK60-6 V3 extended-ID
    framing that the default motor spec selects. Build a CubeMarsAK606v3CAN
    instead.
    Also restore the frame byte layouts that were dropped when mit_mode_packer.py
    and cube_mars_motor_ak606v1_1.py were dissolved into this module, and correct
    the format comments that still named the AK80-6 alone although the
    standard-frame path now carries the AK60-6 V1.1 as well.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
    [cube_mars_motor_can.py, examples_can.py]
2026-09-17 Cover the shared MIT protocol path and rehome the packer tests
    The restructuring moved the AK80-6 V2 / AK60-6 V1.1 MIT implementation into
    CubeMarsBaseCAN, but the suite only exercised the AK60-6 V3 override. Add
    TestMITProtocolByModel, which checks for both base-class motors: the shared
    packer byte order including the new limits=None default, the feedback parser
    round trip, standard- versus extended-frame selection, and the MIT reset sent
    on connect.
    Replace the opaque expected payload in TestMITCommandPath with the packer's
    own output, since the byte order is pinned separately.
    mit_mode_packer_test.py tested a module this branch deletes, so its two
    remaining tests move to utils_test.py,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
    [cube_mars_motor_can_test.py, utils_test.py]
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
